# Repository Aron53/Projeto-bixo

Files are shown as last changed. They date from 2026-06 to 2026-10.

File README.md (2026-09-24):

# Projeto-bixo
Repositório oficial do Grupo 3 no Projeto Bixo 2026. Desenvolvimento de um robô autônomo com ESP32-C3, Ponte H L298N, odometria e integração com Micro-ROS.

---

## 👥 Autores (Membros do Grupo 3)

* **[João Neto]**
* **[Tiago Perini]**
* **[Mateus]**

---

## 📐 Dimensões do Robô (Unidades em mm)

Com base no desenho técnico bidimensional gerado na aba de *Drawing*, a estrutura final do conjunto montado possui as seguintes dimensões limite:

* **Largura Total (ponta a ponta das rodas):** 257.40 mm
* **Comprimento Total do Chassi:** 250.00 mm
* **Altura Estrutural (até a placa superior):** 93.70 mm
* **Altura Total Máxima (até o topo da varinha):** 160.75 mm

---

## 📸 Visualização do Projeto

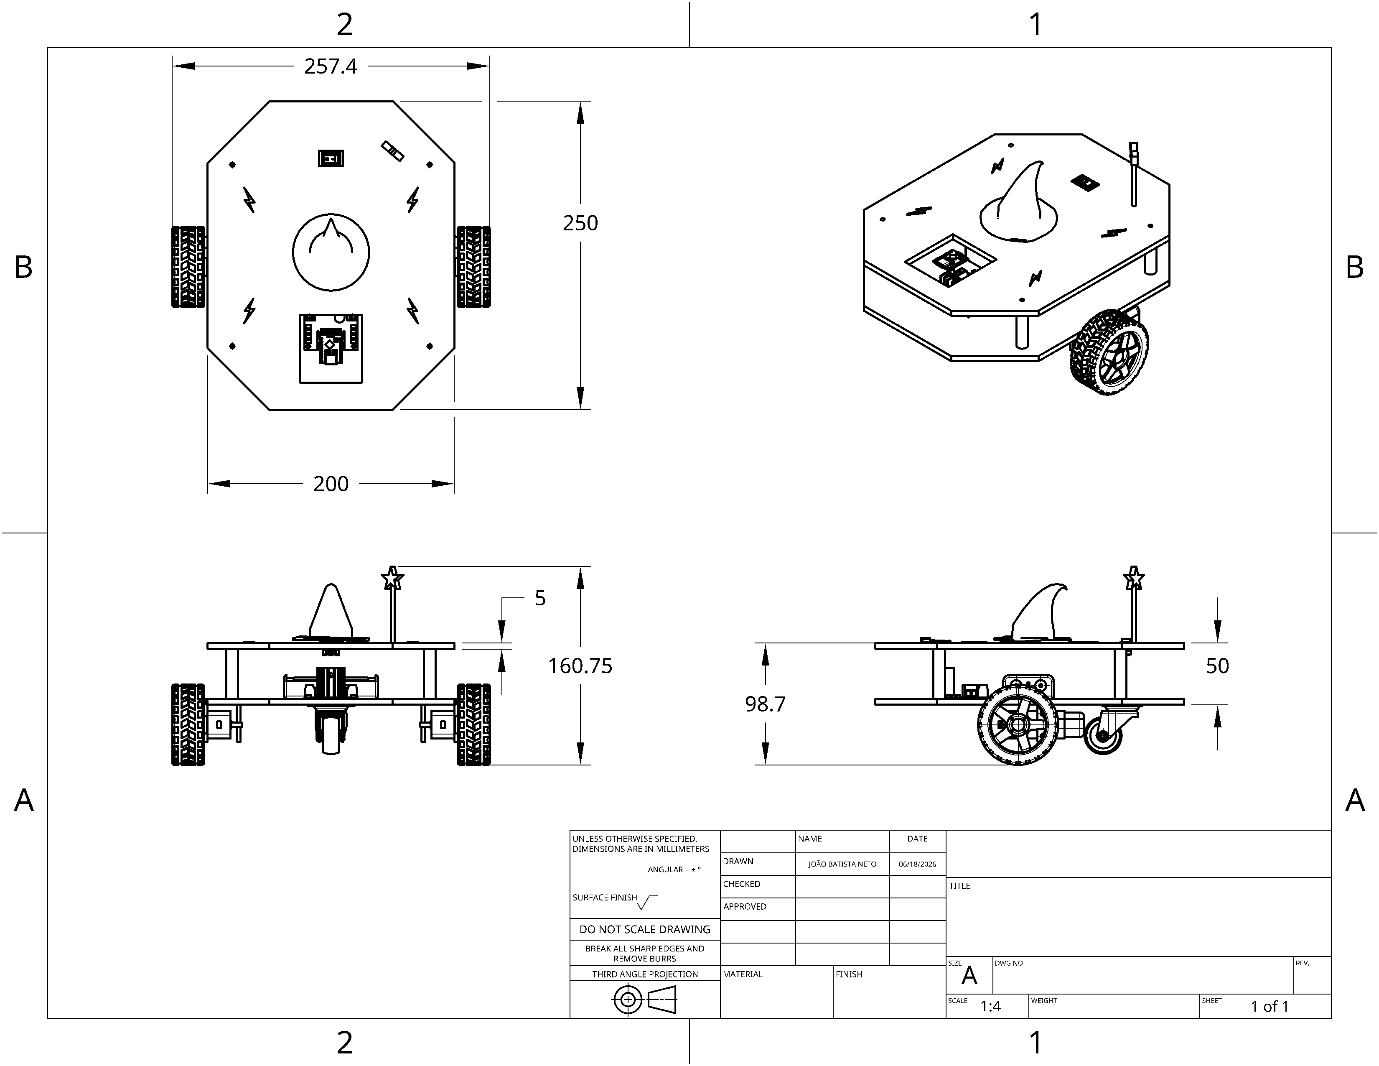
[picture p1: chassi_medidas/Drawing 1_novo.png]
Desenho Técnico do Robô


---

## 🛠️ Escolhas Mecânicas da Equipe

Durante o processo de design e montagem no Onshape, nossa equipe tomou decisões de engenharia estratégicas voltadas para a estabilidade, facilidade de manufatura e manutenção:

1. **Geometria Octogonal:** Escolhida para eliminar cantos vivos de 90°, facilitando manobras e evitando colisões bruscas nas quinas do chassi em ambientes estreitos.
2. **Configuração de Tração Dinâmica:** Optamos por posicionar duas rodas motrizes nas laterais traseiras acopladas diretamente aos motores DC com caixa de redução, combinadas a uma roda na região frontal. Isso garante alto índice de agilidade e raio de giro reduzido.
3. **Distribuição de Componentes e Centro de Massa:** A eletrônica pesada (baterias 18650 e Ponte H L298N) foi fixada estrategicamente mais próxima ao solo, garantindo estabilidade contra tombamentos.
4. **Customização Estética:** Foi adicionado um suporte customizado na chapa superior para o encaixe de uma varinha decorativa na ponta, agregando identidade visual ao projeto sem interferir na dinâmica estrutural.

---

## 📁 Organização Estrutural do Repositório

Os arquivos foram separados dentro do repositório de acordo com as diretrizes de manufatura:

* **`chassi_medidas/`**
  * `Drawing 1.pdf` -> Desenho técnico 2D completo em formato PDF.
  * `Drawing 1.png` -> Imagem do desenho técnico exibida neste README.
  * `modelo_completo_3d.stl` -> Arquivo tridimensional de visualização global do robô montado.
* **`componentes/`**
  * `base_inferior.stl` -> Chapa base inferior do chassi para impressão 3D (unidade em mm).
  * `base_superior.stl` -> Chapa base superior do chassi para impressão 3D (unidade em mm).
  * `espacador.stl` -> Pilares de união e distanciamento entre as chapas.
  * `suporte_motor.stl` -> Presilhas/suportes estruturais para os motores DC amarelos.
  * `varinha_estetica.stl` -> Elemento de personalização do topo.

## Circuito
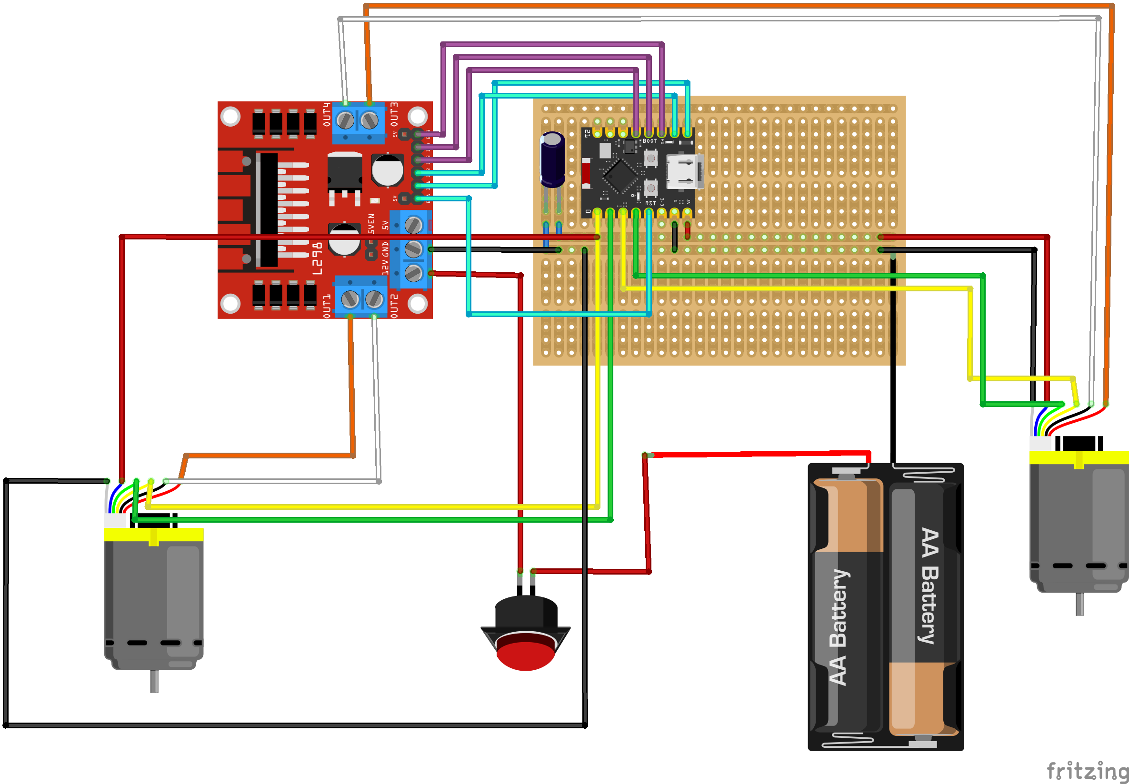
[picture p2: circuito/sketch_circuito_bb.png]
Esquema do circuito


---

## 🧭 Odometria

A odometria estima **onde o robô está** (`x`, `y` e orientação `θ`) a partir do giro das rodas. Cada motor tem um **encoder** que gera pulsos ao girar; contando esses pulsos, calculamos quanto cada roda andou e como o robô se moveu.

### ⚙️ Como funciona

1. **Contagem de pulsos:** uma interrupção dispara a cada pulso do canal A do encoder. O canal B indica o sentido: `HIGH` soma (`ticks++`) e `LOW` subtrai (`ticks--`).
2. **Leitura a cada 50 ms (20 Hz):** o `loop()` usa `millis()`, sem `delay()`. Os contadores são copiados com as interrupções desligadas por um instante, para não corromper os dados.
3. **Cálculo:** a diferença de pulsos desde a última leitura vira distância de cada roda, deslocamento e rotação do robô, e a posição é atualizada (fórmulas abaixo).

### 📏 Parâmetros

| Parâmetro | Símbolo | Variável no código | Valor |
|---|---|---|---|
| Raio da roda | R | `RAIO_RODA` | 0,0336 m |
| Distância entre as rodas | L | `DIST_RODAS` | 0,2140 m |
| Pulsos por volta da roda | N | `PPR_ENCODER` | 330 |
| Tempo de amostragem | Δt | `DT` | 0,05 s |

### 🧮 Fórmulas

Os índices $R$ e $L$ indicam a roda direita e a esquerda.

| O que calcula | Fórmula | Em palavras |
|---|---|---|
| Distância de cada roda | $d = \dfrac{ticks}{N}\cdot 2\pi R$ | fração de volta dada × perímetro da roda |
| Deslocamento do robô | $\Delta s = \dfrac{d_R + d_L}{2}$ | média do que as duas rodas andaram |
| Variação do ângulo | $\Delta\theta = \dfrac{d_R - d_L}{L}$ | a diferença entre as rodas faz o robô girar |
| Posição | $\Delta x = \Delta s\cos\theta_k \quad \Delta y = \Delta s\sin\theta_k$ | decompõe o deslocamento em `x` e `y` |
| Velocidades | $v = \dfrac{\Delta s}{\Delta t} \quad \omega = \dfrac{\Delta\theta}{\Delta t}$ | divide pelo tempo do ciclo (usadas no PID) |

A pose é acumulada a cada ciclo: $x_{k+1} = x_k + \Delta x$, $y_{k+1} = y_k + \Delta y$ e $\theta_{k+1} = \theta_k + \Delta\theta$ (no código, `pos_x`, `pos_y` e `pos_theta`).

---

## 🎮 Controle PID

O controle PID ajusta o PWM enviado a cada motor para que a velocidade real da roda (medida pela odometria) siga uma velocidade desejada (`setpoint`), vinda futuramente do ROS 2.

### ⚙️ Como funciona

1. **Erro:** a cada ciclo de 50 ms, compara a velocidade desejada com a velocidade medida da roda.
2. **Três termos:** o controle soma uma resposta proporcional ao erro atual, uma integral que acumula o erro ao longo do tempo, e uma derivada que reage à taxa de variação do erro.
3. **Saída em PWM:** a soma dos três termos vira o sinal enviado à Ponte H (0–255), limitado nesse intervalo, e o sinal do PWM decide o sentido de giro do motor.

### 🧮 Fórmulas

| O que calcula | Fórmula | Em palavras |
|---|---|---|
| Erro | $e_k = setpoint - v_{medida}$ | quanto falta para atingir a velocidade desejada |
| Termo Proporcional | $P = K_p \cdot e_k$ | resposta proporcional ao erro atual |
| Termo Integral | $I = K_i \cdot \sum e_k \cdot \Delta t$ | corrige erro acumulado (ex: atrito constante) |
| Termo Derivativo | $D = K_d \cdot \dfrac{e_k - e_{k-1}}{\Delta t}$ | reage à velocidade de variação do erro, amortece oscilações |
| Saída (PWM) | $u = P + I + D$ | soma dos três termos, limitada a [0, 255] |

$K_p$, $K_i$ e $K_d$ são os ganhos do controlador, ainda a serem ajustados por tentativa e erro.

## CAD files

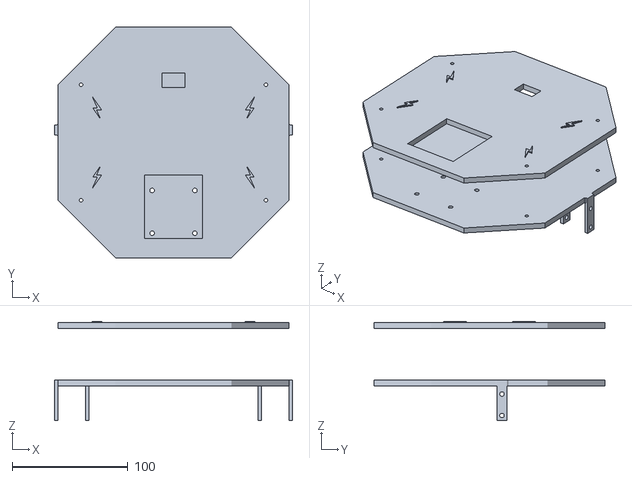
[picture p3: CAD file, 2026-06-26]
componentes/bases - base inferior.stl
206.0 x 200.0 x 86.0

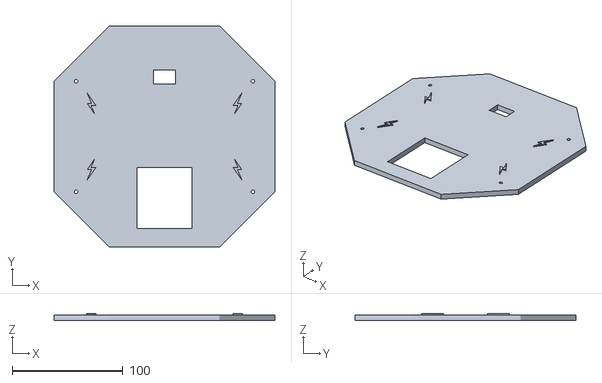
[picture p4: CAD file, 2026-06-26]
componentes/bases - base superior.stl
200.0 x 200.0 x 6.00

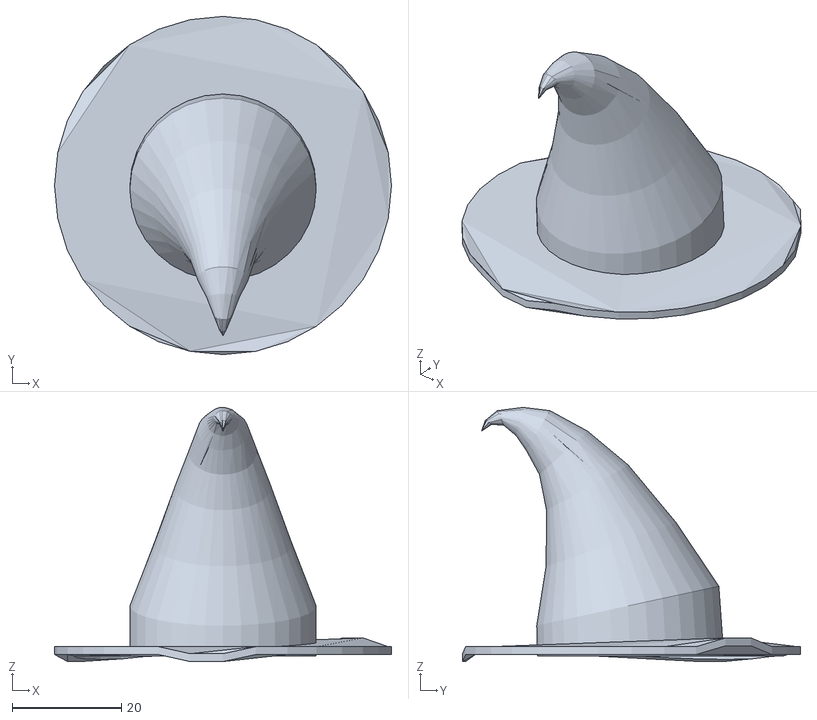
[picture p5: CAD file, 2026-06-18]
componentes/chapeu.stl
61.8 x 62.0 x 46.6

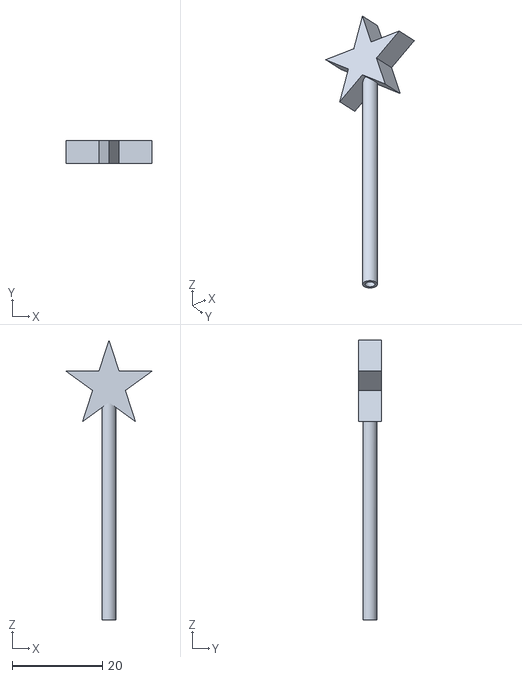
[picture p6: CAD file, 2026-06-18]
componentes/varinha.stl
19.0 x 5.00 x 62.0

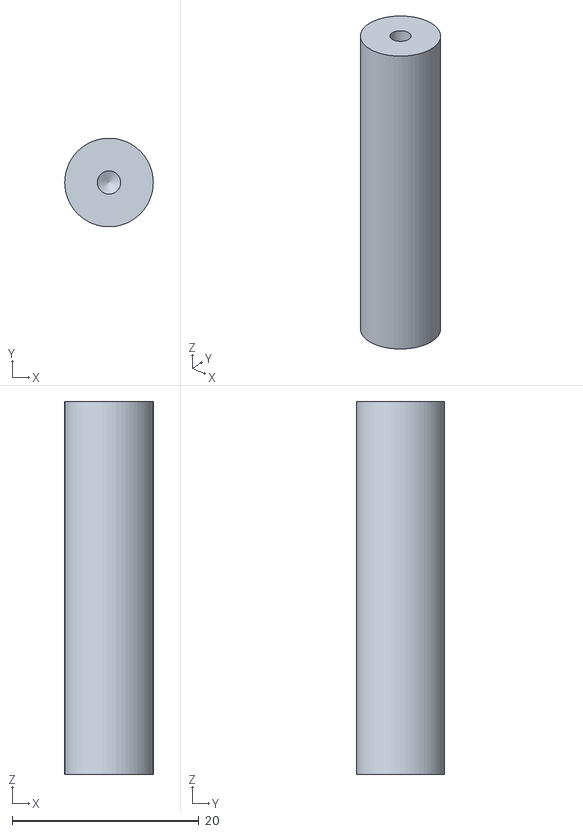
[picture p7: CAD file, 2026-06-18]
componentes/espaçador.stl
9.50 x 9.49 x 40.0

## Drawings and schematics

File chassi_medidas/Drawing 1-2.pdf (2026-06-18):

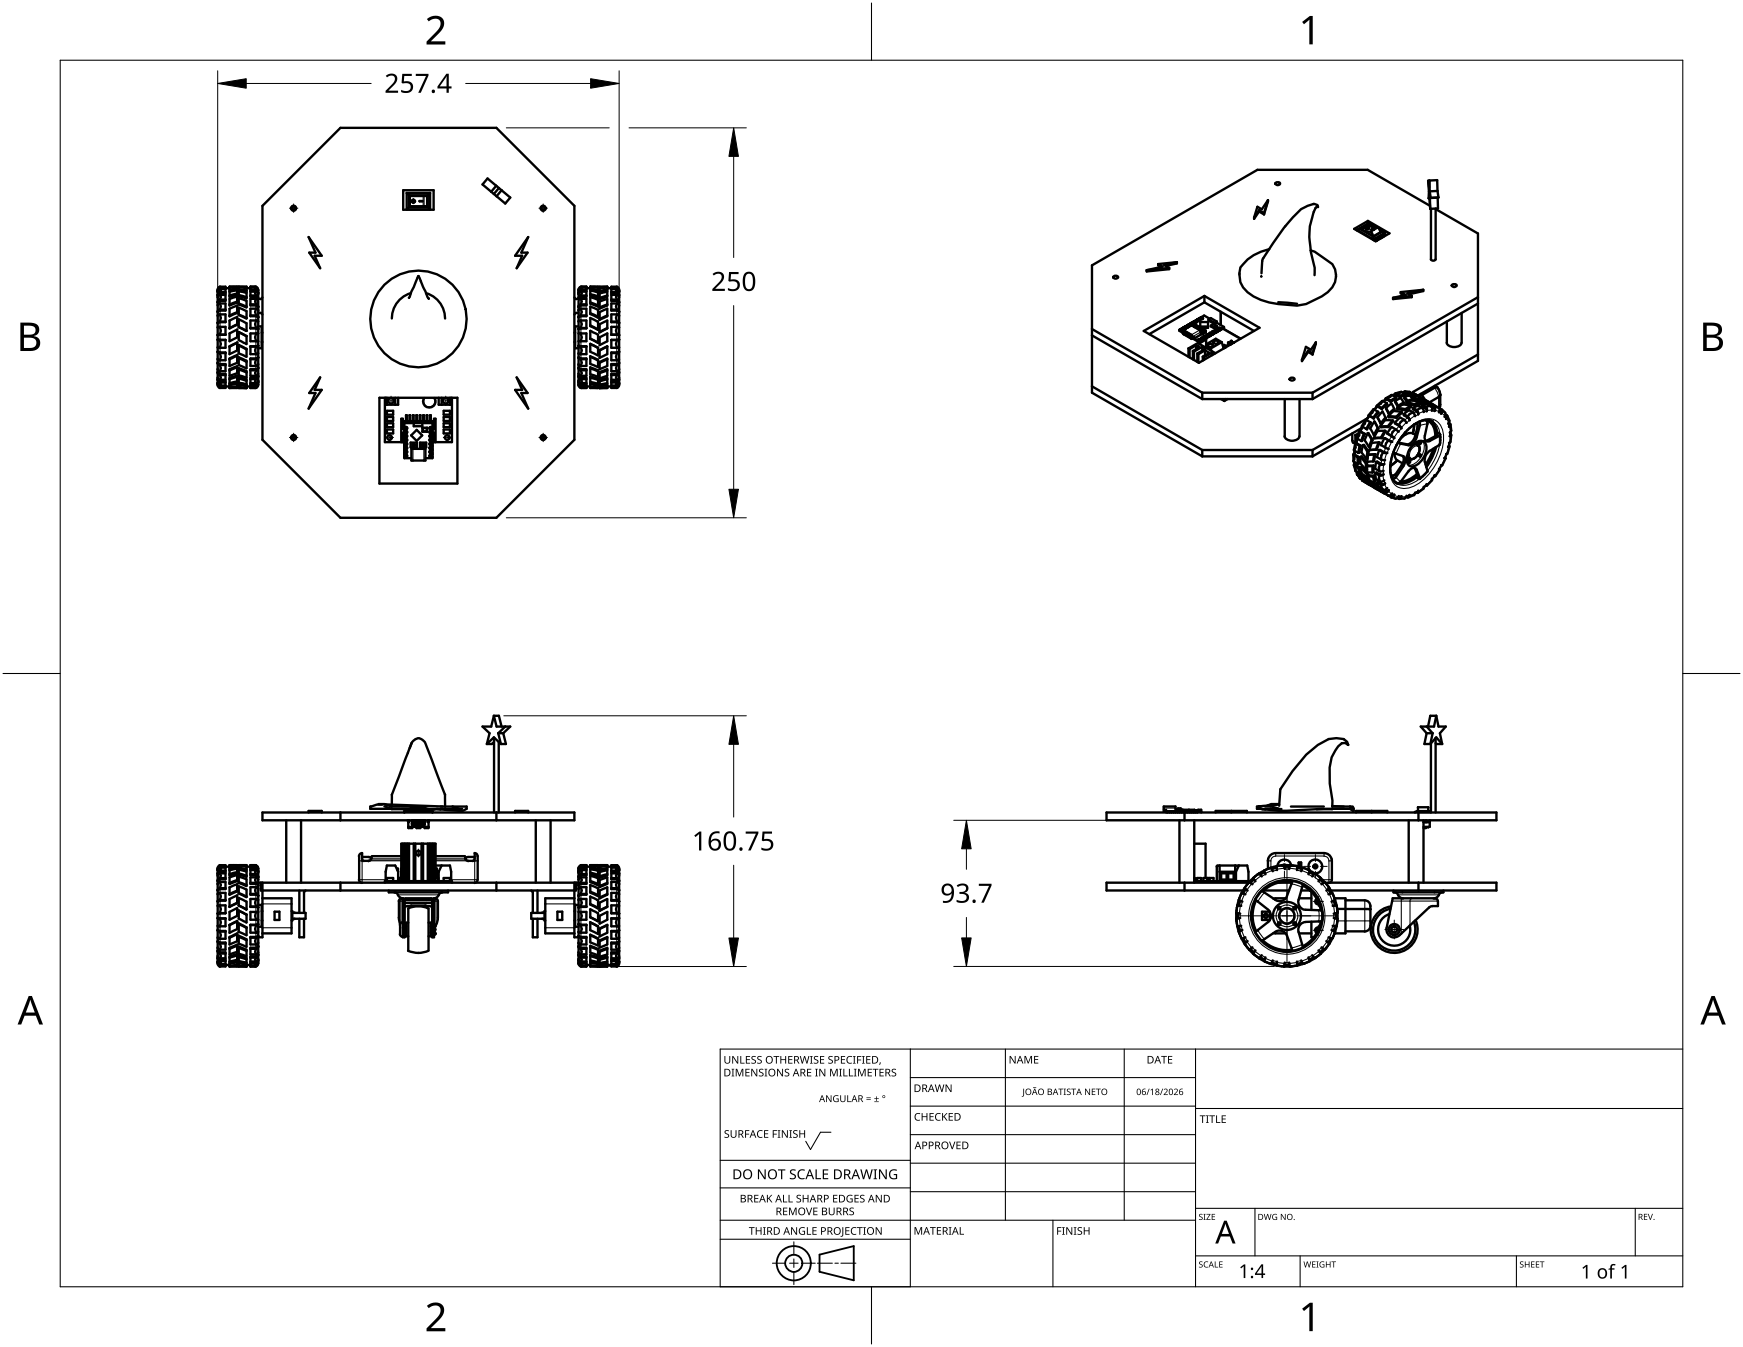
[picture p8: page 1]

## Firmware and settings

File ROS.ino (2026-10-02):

#include <Arduino.h>
#include <WiFi.h>
#include <micro_ros_platformio.h>

#include <rcl/rcl.h>
#include <rcl/error_handling.h>
#include <rclc/rclc.h>
#include <rclc/executor.h>
#include <geometry_msgs/msg/twist.h>
#include <geometry_msgs/msg/point.h>

#include "secrets.h"

// ==========================================
// 1. DEFINICAO DE PINOS
// ==========================================
#define ENC_IN_ESQ_A 0
#define ENC_IN_ESQ_B 1
#define ENC_IN_DIR_A 2
#define ENC_IN_DIR_B 3

#define MOT_ESQ_PWM 4
#define MOT_ESQ_IN1 5
#define MOT_ESQ_IN2 6
#define MOT_DIR_PWM 7
#define MOT_DIR_IN1 8
#define MOT_DIR_IN2 9

// ==========================================
// 1B. GEOMETRIA DO ROBO E PARAMETROS (Do segundo código)
// ==========================================
const float RAIO_RODA = 0.0336f;
const float DIST_RODAS = 0.2140f;
const float PPR_ENCODER = 330.0f;

const float VEL_LINEAR_MAX_MS = 0.3f;   
const float VEL_ANGULAR_MAX_RADS = 2.0f; 

const float KP_LINEAR = 0.6f;
const float KP_ANGULAR = 1.5f;

// Ganhos do PID (Ajustar conforme necessário)
const float Kp = 1.0f;
const float Ki = 0.0f;
const float Kd = 0.0f;

// ==========================================
// 2. VARIAVEIS GLOBAIS DE SISTEMA (Do segundo código)
// ==========================================
volatile long ticks_esq = 0;
volatile long ticks_dir = 0;
float ultimos_ticks_esq = 0;
float ultimos_ticks_dir = 0;

volatile float setpoint_esq = 0.0f;
volatile float setpoint_dir = 0.0f;

// Variáveis para compatibilidade com a cinemática do 1º código
volatile float setpoint_omega_esq = 0.0f;
volatile float setpoint_omega_dir = 0.0f;

// Posição
float pos_atual_x = 0.0f;
float pos_atual_y = 0.0f;
float pos_theta = 0.0f;

// Variáveis de Erro do PID
float erro_int_esq = 0.0f;
float erro_int_dir = 0.0f;
float erro_anterior_esq = 0.0f;
float erro_anterior_dir = 0.0f;

const float DT = 0.05f; 
unsigned long tempo_anterior = 0;
const int INTERVALO_AMOSTRAGEM_MS = 50; 

// ==========================================
// 3. MICRO-ROS (Estrutura do primeiro código)
// ==========================================
rcl_subscription_t cmd_vel_subscriber;
rcl_subscription_t goal_subscriber;
geometry_msgs__msg__Twist cmd_vel_msg;
geometry_msgs__msg__Point goal_msg;
rclc_executor_t executor;
rclc_support_t support;
rcl_allocator_t allocator;
rcl_node_t node;

#define RCCHECK(fn) \
  { \
    rcl_ret_t rc = fn; \
    if (rc != RCL_RET_OK) error_loop(); \
  }
#define RCSOFTCHECK(fn) \
  { \
    rcl_ret_t rc = fn; \
    (void)rc; \
  }

void error_loop() {
  while (true) {
    Serial.println("error_loop: rcl init falhou");
    delay(500);
  }
}

// ==========================================
// 4. INTERRUPCOES DE HARDWARE (ISRs - Do segundo código)
// ==========================================
void IRAM_ATTR isr_encoder_esq() {
  if (digitalRead(ENC_IN_ESQ_B) == HIGH) {
    ticks_esq++;
  } else {
    ticks_esq--;
  }
}

void IRAM_ATTR isr_encoder_dir() {
  if (digitalRead(ENC_IN_DIR_B) == HIGH) {
    ticks_dir++;
  } else {
    ticks_dir--;
  }
}

// ==========================================
// 5. FUNCOES DE CALCULO E CONTROLE (Do segundo código)
// ==========================================
void calcula_odometria() {
  noInterrupts();
  long ticks_atuais_esq = ticks_esq;
  long ticks_atuais_dir = ticks_dir;
  interrupts();

  long delta_ticks_esq = ticks_atuais_esq - (long)ultimos_ticks_esq;
  long delta_ticks_dir = ticks_atuais_dir - (long)ultimos_ticks_dir;

  ultimos_ticks_dir = ticks_atuais_dir;
  ultimos_ticks_esq = ticks_atuais_esq;

  float Delta_rad_esq = ((float)delta_ticks_esq / PPR_ENCODER) * 2.0f * PI;
  float Delta_rad_dir = ((float)delta_ticks_dir / PPR_ENCODER) * 2.0f * PI;

  float V_Esq = Delta_rad_esq * RAIO_RODA / DT;
  float V_Dir = Delta_rad_dir * RAIO_RODA / DT;

  // Atualiza setpoints locais usando os setpoints angulares gerados pelo ROS (Cinemática do 1º código)
  setpoint_esq = setpoint_omega_esq * RAIO_RODA;
  setpoint_dir = setpoint_omega_dir * RAIO_RODA;

  float PWM_esquerdo = controle_pid(setpoint_esq, V_Esq, erro_int_esq, erro_anterior_esq);
  float PWM_direito  = controle_pid(setpoint_dir, V_Dir, erro_int_dir, erro_anterior_dir);

  aciona_motores(PWM_esquerdo, PWM_direito);
}

float controle_pid(float setpoint, float medida, float &erro_int, float &erro_anterior) {
  float erro = setpoint - medida;

  float proporcional = Kp * erro;
  float derivada = Kd * (erro - erro_anterior) / DT;
  erro_int += erro * DT;
  float integral = Ki * erro_int;

  erro_anterior = erro;

  float saida = proporcional + integral + derivada;
  return constrain(saida, -255.0f, 255.0f);
}

void aciona_motores(float PWM_esquerdo, float PWM_direito) {
  if (PWM_esquerdo < 0) {
    digitalWrite(MOT_ESQ_IN1, LOW);
    digitalWrite(MOT_ESQ_IN2, HIGH);
    analogWrite(MOT_ESQ_PWM, (int)abs(PWM_esquerdo));
  } else {
    digitalWrite(MOT_ESQ_IN1, HIGH);
    digitalWrite(MOT_ESQ_IN2, LOW);
    analogWrite(MOT_ESQ_PWM, (int)abs(PWM_esquerdo));
  }

  if (PWM_direito < 0) {
    digitalWrite(MOT_DIR_IN1, LOW);
    digitalWrite(MOT_DIR_IN2, HIGH);
    analogWrite(MOT_DIR_PWM, (int)abs(PWM_direito));
  } else {
    digitalWrite(MOT_DIR_IN1, HIGH);
    digitalWrite(MOT_DIR_IN2, LOW);
    analogWrite(MOT_DIR_PWM, (int)abs(PWM_direito));
  }
}

// ==========================================
// 6. CINEMATICA DIFERENCIAL + INTEGRACAO ROS 2 (Do primeiro código)
// ==========================================
void aplica_velocidade(float v, float w) {
  v = constrain(v, -VEL_LINEAR_MAX_MS, VEL_LINEAR_MAX_MS);
  w = constrain(w, -VEL_ANGULAR_MAX_RADS, VEL_ANGULAR_MAX_RADS);

  float vel_linear_esq = v - (w * DIST_RODAS / 2.0f);
  float vel_linear_dir = v + (w * DIST_RODAS / 2.0f);

  setpoint_omega_esq = vel_linear_esq / RAIO_RODA;
  setpoint_omega_dir = vel_linear_dir / RAIO_RODA;
}

void cmd_vel_callback(const void *msgin) {
  const geometry_msgs__msg__Twist *msg = (const geometry_msgs__msg__Twist *)msgin;
  aplica_velocidade((float)msg->linear.x, (float)msg->angular.z);
}

void coordenada_para_velocidade(float x, float y, float *v, float *w) {
  float distancia = sqrtf(x * x + y * y);
  float angulo_para_alvo = atan2f(x, y); 

  *w = KP_ANGULAR * angulo_para_alvo;
  *v = KP_LINEAR * distancia;

  if (fabsf(angulo_para_alvo) > 0.3f) {
    *v = 0.0f;
  }
}

void goal_callback(const void *msgin) {
  const geometry_msgs__msg__Point *msg = (const geometry_msgs__msg__Point *)msgin;
  float v, w;
  coordenada_para_velocidade((float)msg->x, (float)msg->y, &v, &w);
  aplica_velocidade(v, w);
}

// ==========================================
// SETUP INICIAL
// ==========================================
void setup() {
  Serial.begin(115200);

  pinMode(ENC_IN_ESQ_A, INPUT_PULLUP);
  pinMode(ENC_IN_ESQ_B, INPUT_PULLUP);
  pinMode(ENC_IN_DIR_A, INPUT_PULLUP);
  pinMode(ENC_IN_DIR_B, INPUT_PULLUP);

  attachInterrupt(digitalPinToInterrupt(ENC_IN_ESQ_A), isr_encoder_esq, RISING);
  attachInterrupt(digitalPinToInterrupt(ENC_IN_DIR_A), isr_encoder_dir, RISING);

  pinMode(MOT_ESQ_PWM, OUTPUT);
  pinMode(MOT_ESQ_IN1, OUTPUT);
  pinMode(MOT_ESQ_IN2, OUTPUT);
  pinMode(MOT_DIR_PWM, OUTPUT);
  pinMode(MOT_DIR_IN1, OUTPUT);
  pinMode(MOT_DIR_IN2, OUTPUT);

  // Setup do micro-ROS (Lógica completa do primeiro código)
  IPAddress agent_ip;
  agent_ip.fromString(AGENT_IP);
  set_microros_wifi_transports((char *)WIFI_SSID, (char *)WIFI_PASS,
                                agent_ip, AGENT_PORT);
  WiFi.setSleep(false);
  delay(2000);

  allocator = rcl_get_default_allocator();

  RCCHECK(rclc_support_init(&support, 0, NULL, &allocator));
  RCCHECK(rclc_node_init_default(&node, "bixo_esp32c3_node", "", &support));

  RCCHECK(rclc_subscription_init_default(
      &cmd_vel_subscriber, &node,
      ROSIDL_GET_MSG_TYPE_SUPPORT(geometry_msgs, msg, Twist), "cmd_vel"));

  RCCHECK(rclc_subscription_init_default(
      &goal_subscriber, &node,
      ROSIDL_GET_MSG_TYPE_SUPPORT(geometry_msgs, msg, Point), "bixo/goal"));

  RCCHECK(rclc_executor_init(&executor, &support.context, 2, &allocator));
  RCCHECK(rclc_executor_add_subscription(&executor, &cmd_vel_subscriber, &cmd_vel_msg,
                                        &cmd_vel_callback, ON_NEW_DATA));
  RCCHECK(rclc_executor_add_subscription(&executor, &goal_subscriber, &goal_msg,
                                        &goal_callback, ON_NEW_DATA));

  Serial.println("Sistema Iniciado. Aguardando inicio dos ciclos de controle...");
}

// ==========================================
// LOOP PRINCIPAL
// ==========================================
void loop() {
  unsigned long tempo_atual = millis();

  if (tempo_atual - tempo_anterior >= INTERVALO_AMOSTRAGEM_MS) {
    calcula_odometria();

    Serial.print("Ticks_Esq:");
    Serial.print(ticks_esq);
    Serial.print("\tTicks_Dir:");
    Serial.print(ticks_dir);
    Serial.print("\tSetpoint_Esq(rad/s):");
    Serial.print(setpoint_omega_esq);
    Serial.print("\tSetpoint_Dir(rad/s):");
    Serial.println(setpoint_omega_dir);

    tempo_anterior = tempo_atual;
  }

  RCSOFTCHECK(rclc_executor_spin_some(&executor, RCL_MS_TO_NS(10)));
}

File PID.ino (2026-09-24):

#include <Arduino.h>

// ==========================================
// 1. DEFINICAO DE PINOS (O grupo deve adaptar para o seu Hardware)
// ==========================================
// Pinos dos Encoders (Escolher pinos que suportam interrupcao de hardware)
#define ENC_IN_ESQ_A 0
#define ENC_IN_ESQ_B 1
#define ENC_IN_DIR_A 2
#define ENC_IN_DIR_B 3

// Pinos da Ponte H
#define MOT_ESQ_PWM 4
#define MOT_ESQ_IN1 5
#define MOT_ESQ_IN2 6
#define MOT_DIR_PWM 7
#define MOT_DIR_IN1 8
#define MOT_DIR_IN2 9

// Raio da roda em metros
const float RAIO_RODA = 0.0336;

// Distancia das rodas em metros
const float DIST_RODAS = 0.2140;

//Pulsos por revolução do eixo da roda
const float PPR_ENCODER = 330;

// ==========================================
// 2. VARIAVEIS GLOBAIS DE SISTEMA
// ==========================================
// O termo 'volatile' informa ao compilador que a variavel pode mudar a qualquer momento
// fora do fluxo normal do codigo (ou seja, dentro das interrupcoes).
volatile long ticks_esq = 0;
volatile long ticks_dir = 0;
float ultimos_ticks_esq = 0;
float ultimos_ticks_dir = 0;

//Posição 
float pos_atual_x = 0.0;
float pos_atual_y = 0.0;
float pos_theta = 0.0;

//tempo de amostragem (mudar depois)
const float DT = 0.05; 

// Variaveis para garantir que o loop principal rode em frequencia fixa (Sem delay!)
unsigned long tempo_anterior = 0;
const int INTERVALO_AMOSTRAGEM_MS = 50; // Roda o controle a 20Hz

// ==========================================
// 3. CABECALHOS PARA O MICRO-ROS (PARA A AULA 5)
// ==========================================
/*
* ATENCAO ALUNOS: Deixem esta secao comentada durante as Aulas 1 a 4.
* Voces a ativarao na Aula 5 para transformar o microcontrolador em um No ROS 2.
// #include <micro_ros_arduino.h>
// #include <rcl/rcl.h>
// #include <rclc/rclc.h>
// #include <rclc/executor.h>
// #include <geometry_msgs/msg/twist.h>
// #include <nav_msgs/msg/odometry.h>
// rcl_publisher_t odom_publisher;
// rcl_subscription_t cmd_vel_subscriber;
*/

// ==========================================
// 4. INTERRUPCOES DE HARDWARE (ISRs)
// ==========================================
// IRAM_ATTR aloca a funcao na memoria RAM do microcontrolador, garantindo execucao extremamente rapida.
void IRAM_ATTR isr_encoder_esq() {
    // TODO (Aula 3): Voces precisam ler o estado do pino B para determinar
    // se a roda esta indo para frente ou para tras.
    // Por enquanto, o codigo apenas conta para cima:
    if (digitalRead(ENC_IN_ESQ_B) == HIGH){
      ticks_esq++;
    }
    else ticks_esq--;

}

void IRAM_ATTR isr_encoder_dir() {
    // TODO (Aula 3): Implementar a logica de quadratura para a roda direita.
    if (digitalRead(ENC_IN_DIR_B) == HIGH){
      ticks_dir++;
    }
    else ticks_dir--;
}

// ==========================================
// 5. FUNCOES DE CALCULO E CONTROLE (AULAS 3 E 4)
// ==========================================
void calcula_odometria() {
    // O resgate de variaveis volatile precisa ser rapido.
    // Desligamos as interrupcoes por um microssegundo para copiar os valores e nao corromper os dados.
    noInterrupts();
    long ticks_atuais_esq = ticks_esq;
    long ticks_atuais_dir = ticks_dir;
    interrupts();


    long delta_ticks_esq = ticks_atuais_esq - ticks_esq;
    long delta_ticks_dir = ticks_atuais_dir - ticks_esq;

    ultimos_ticks_dir = ticks_atuais_dir;
    ultimos_ticks_esq = ticks_atuais_esq;

    // TODO (Aula 3): Com os ticks atuais e o tempo percorrido (INTERVALO_AMOSTRAGEM_MS),
    // calculem a Velocidade Angular de cada roda (rad/s).
    // Em seguida, calculem a Velocidade Linear (m/s) e Angular (rad/s) do centro do robo.
    float Delta_rad_esq = (delta_ticks_esq/PPR_ENCODER)*2*PI;
    float Delta_rad_dir = (delta_ticks_dir/PPR_ENCODER)*2*PI;

    float Vel_Ang_Dir = (Delta_rad_dir/DT);
    float Vel_Ang_Esq = (Delta_rad_esq/DT);

    float V_Dir = (Delta_rad_dir*RAIO_RODA);
    float V_Esq = (Delta_rad_esq*RAIO_RODA);
    float Vel_Linear = (V_Dir + V_Esq)/2;

    float VarAng = (Delta_rad_esq - Delta_rad_dir)/DIST_RODAS;
    float Vel_Ang_centro = (VarAng/DT);

    //setpoint arbitrario por enquanto
    float erro_int_esq = setpoint_esq - V_Esq
    float erro_int_dir = setpoint_dir - V_Dir
}

float controle_pid(float setpoint, float medida, float &erro_int, float &erro_anterior) {
    // TODO (Aula 4): Implementar o Controle em Malha Fechada
    // 1. Calcular o Erro (Setpoint desejado - Velocidade Real das rodas)
    // 2. Calcular as acoes Proporcional (P), Integral (I) e Derivativa (D)
    // 3. Converter o resultado matematico em sinal PWM (0 a 255) para enviar para a Ponte H.
    float erro = setpoint - medida;

    float proporcional = Kp*erro;

    float derivada = Kd*(erro - erro_anterior/ DT);

    erro_int += erro*DT

    float integral = Ki*erro_int

    erro_anterior = erro

    float saida = proporcional + integral + derivada 

    if saida > 255:
        saida = 255;
    

}

void aciona_motores(float PWM_esp, float PWM_dir) {
    if PWM_esquerdo < 0:
        digitalWrite(MOT_ESQ_IN1, HIGH);
        digitalWrite(MOT_ESQ_IN2, LOW);
        analogWrite(MOT_ESQ_PWM, abs(PWM_esquerdo));
    if PWM_esquerdo > 0:
        digitalWrite(MOT_ESQ_IN1, HIGH);
        digitalWrite(MOT_ESQ_IN2, LOW);
        analogWrite(MOT_ESQ_PWM, abs(PWM_esquerdo));
    if PWM_direito < 0:
        digitalWrite(MOT_ESQ_IN1, HIGH);
        digitalWrite(MOT_ESQ_IN2, LOW);
        analogWrite(MOT_ESQ_PWM, abs(PWM_direito));
    if PWM_direito > 0:
        digitalWrite(MOT_ESQ_IN1, HIGH);
        digitalWrite(MOT_ESQ_IN2, LOW);
        analogWrite(MOT_ESQ_PWM, abs(PWM_direito));

}

// ==========================================
// SETUP INICIAL
// ==========================================
void setup() {
    Serial.begin(115200);

    // Configuracao dos pinos dos encoders (INPUT_PULLUP previne ruidos caso o encoder seja do tipo open-collector)
    pinMode(ENC_IN_ESQ_A, INPUT_PULLUP);
    pinMode(ENC_IN_ESQ_B, INPUT_PULLUP);
    pinMode(ENC_IN_DIR_A, INPUT_PULLUP);
    pinMode(ENC_IN_DIR_B, INPUT_PULLUP);

    // Acoplando as interrupcoes aos pinos A de cada motor.
    // "RISING" significa que a interrupcao dispara quando o sinal sobe de 0V para 3.3V/5V.
    attachInterrupt(digitalPinToInterrupt(ENC_IN_ESQ_A), isr_encoder_esq, RISING);
    attachInterrupt(digitalPinToInterrupt(ENC_IN_DIR_A), isr_encoder_dir, RISING);

    // TODO: Configurar os pinos da Ponte H como saidas (OUTPUT) e configurar os canais PWM.

    // ==========================================
    // SETUP DO MICRO-ROS (Comentado para Aulas 1-4)
    // ==========================================
    // set_microros_transports();
    // rclc_support_init(...);
    // rclc_node_init_default(...);
    // rclc_publisher_init_default(...);

    Serial.println("Sistema Iniciado. Aguardando inicio dos ciclos de controle...");
}
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

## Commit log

2026-06-18 arquivos stl dos componentes
    [bases - base inferior.stl, bases - base superior.stl, chapeu.stl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]
2026-06-18 alteração do drawing (adição de mais medidas)
2026-06-26 Diminuição da base
    [bases - base inferior.stl, bases - base superior.stl]
2026-06-26 Sketch do circuito inicial
    [sketch_circuito.fzz]
2026-06-30 Adição do png do circuito
2026-09-18 Codigo odometria arduino
    Utiliza a leitura do encoder para calcular o deslocamento do motor utilizando C++ no arduino IDE. Atravez de dois sensores vemos quanto o motor girou, a utilização de dois sensores auxilia na medida 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
2026-09-18 codigo odometria ajustado
    Codigo da odometria atualizado.
2026-09-21 Delete Odometria.ino
    Esse ai tava errado, só não conta pro avaliador ;)
2026-09-21 Odometria.ino
    Código certo blaster correto 7 rebirth pro max
2026-09-21 Rename Codigo_Semana_3_Grupo_3.ino to Odometria.ino
    mudança pro nome certo ;)
2026-09-24 arquivo de codigo PID
2026-09-25 Delete index.html
    deletando para adicionar o novo
2026-09-25 index.html
    Atualizando a página do robô com a adição do PID.
2026-10-02 Add files via upload
    odometria final
